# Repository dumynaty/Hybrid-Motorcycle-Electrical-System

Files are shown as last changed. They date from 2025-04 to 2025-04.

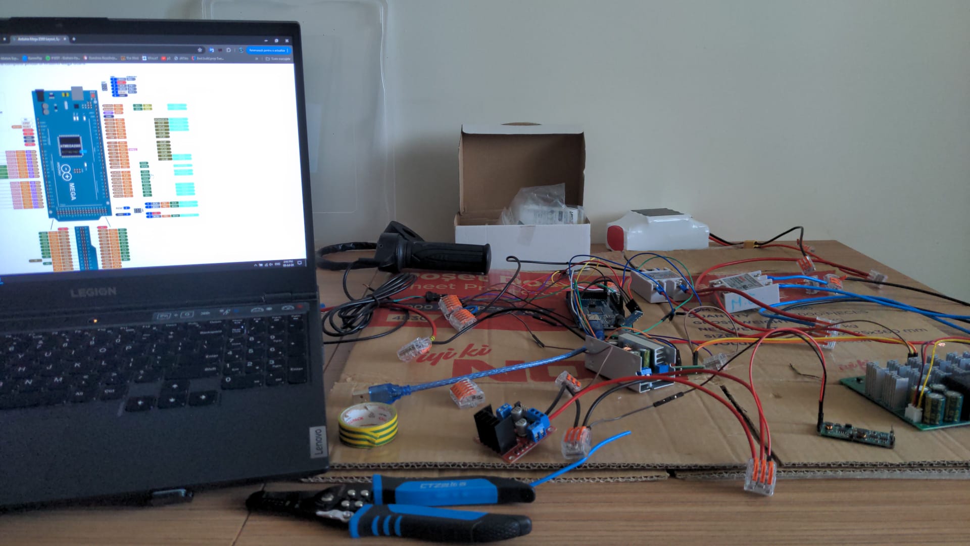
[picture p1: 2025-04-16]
Components/Images/Testing Image 1.png

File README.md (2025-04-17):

# Hybrid Motorcycle Electrical System

## Description
This project focuses on designing an electrical system for a motorcycle, combining a DC motor with a combustion engine to create a plug-in hybrid vehicle.

#### Note: Used as a thesis in Robotics Engineering. Some elements (3D models, technical drawings, sizing & load calculations etc.) have been left out.

### Overview elements
* Aim and conceptual background: read **Project Design** and **Thesis Description**
* Electrical system schematic: access **Fritzing** folder for schematic file or image
* Components used: access **Components** folder for list and images
* Integration logic: access **Code** folder

### General outline
Main components:
* Combustion engine and DC motor
* Additional motors for controlling the engine's gear and speed cable (worm gear, servo)
* Motor Drivers
* Battery to power the motor and other electrical components
* Ability to charge the battery during operation
* Sensors: Hall, Gyroscope, Voltage, Current
* Electronic switches (E-switches) to control current flow paths
* Voltage regulators
* Microcontrollers: Arduino Mega (program logic), ESP32 (Bluetooth communication)

### Functionality
The system is designed to accomplish the following:
* DC motor used as primary propulsion source at speeds up to 20 km/h
* Engine's power for higher speeds
* Smooth transition when switching power sources
* Using DC motor: throttle lever provides data to the microcontroller, which then regulates current delivery via the motor driver
* Using engine: throttle lever provides data to the microcontroller, which controls the clutch actuator motor and regulates the servomotor connected to the throttle cable and, under certain conditions, also initiates battery charging

### Further development possibilities
The system can be significantly improved by integrating the regulators, sensors, drivers, and other components into a single custom PCB.
Additional sensors may be added, such as a temperature sensor, to expand monitoring capabilities.
Further optimization of the microcontroller code can enhance performance and efficiency.
A visual interface can also be developed to display the data received via Bluetooth communication.

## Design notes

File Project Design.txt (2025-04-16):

	Initial Concept

This project aims to convert a regular pedal bicycle into a hybrid vehicle by integrating an 80cc combustion engine and an electric motor, allowing it to switch between them automatically based on wheel RPM data from a sensor. This optimizes energy consumption and performance in various road conditions.

Initially, an 80cc engine was planned, but due to reliability issues, it was replaced with a more robust 125cc Lifan engine. This engine includes a magneto that supplies 12V for charging and powering other components. The throttle and clutch require strong cables, so more powerful motors were chosen to control them.
The electric motor chosen is a 350W, 9.47Nm unit, controlled by a dedicated driver and a throttle handle connected to an Arduino Mega (upgraded from Uno for more complex functionality). The vehicle uses sensors (RPM and gyroscope) for automatic motor switching and safety. If the rider falls, the gyroscope cuts off power to the motors.
A UPS module (with a 18650 battery) ensures the Arduino remains powered at all times. An ESP32 module sends real-time data via Bluetooth to a smartphone — including motor RPM, battery status, etc.
Charging the batteries is managed using voltage regulators, e-switch modules, and safety measures (to prevent reverse current). The system is a carefully engineered blend of electrical and mechanical integration.

	Electrical Architecture
	
Key considerations in system architecture include:
Selecting the main electric motor, batteries, and microcontroller
Choosing motors for clutch and throttle cable control
Selecting appropriate motor drivers
Integrating a throttle (potentiometer-based)
RPM and tilt (gyro) sensors for control and safety
Voltage regulators (buck/boost) for component power needs
Modules for current monitoring and battery charging
UPS backup for Arduino
Wiring with proper connectors and terminal blocks

	Requirements Analysis & Hierarchy
	
The development process prioritized the following:
Correct selection and sizing of the main electric and combustion motors
Appropriate battery selection for power and autonomy
A microcontroller (Arduino Mega) to manage data and control flow
Motor drivers suited for the system's power requirements
Ergonomic speed throttle compatible with the handlebar
Sensors (RPM, gyroscope) for automatic control and safety
Voltage regulation modules to power components safely
Battery charging system design using boost converters, e-switches, and safety diodes
Reliable wiring and connectors to ensure stable power delivery
Testing and tuning will follow the schematic to ensure smooth operation.

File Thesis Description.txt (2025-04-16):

This bachelor's thesis focuses on designing a hybrid system for a motorcycle, combining an electric motor with a combustion engine to enhance energy efficiency and reduce emissions. The project addresses the global shift toward sustainable transport by offering a transitional solution between conventional and fully electric vehicles.

Main Goal:
To build an integrated system that automatically switches between electric and thermal propulsion based on real-time usage, ensuring efficient energy use, safe operation, and smooth performance.

Key Steps:

Identify and classify main and secondary components (motors, battery, driver, etc.).
Design the system based on vehicle weight and power requirements.
Use simulations, software tools, and physical testing for validation.

Outcomes:
A working hybrid prototype for small vehicles.
Lower emissions, better energy performance.
Demonstrated integration feasibility of hybrid tech in motorcycles.

Limitations:
Testing was limited to controlled environments.
Real-world performance still to be evaluated.

Impact:

Environmental: Reduced carbon footprint and air pollution.
Economic: Lower user costs, potential for market expansion.
Scientific: Contributes to the knowledge base on compact hybrid systems.

Originality:
Innovative integration approach tailored for motorcycles, offering a valuable framework for future development in green mobility tech.

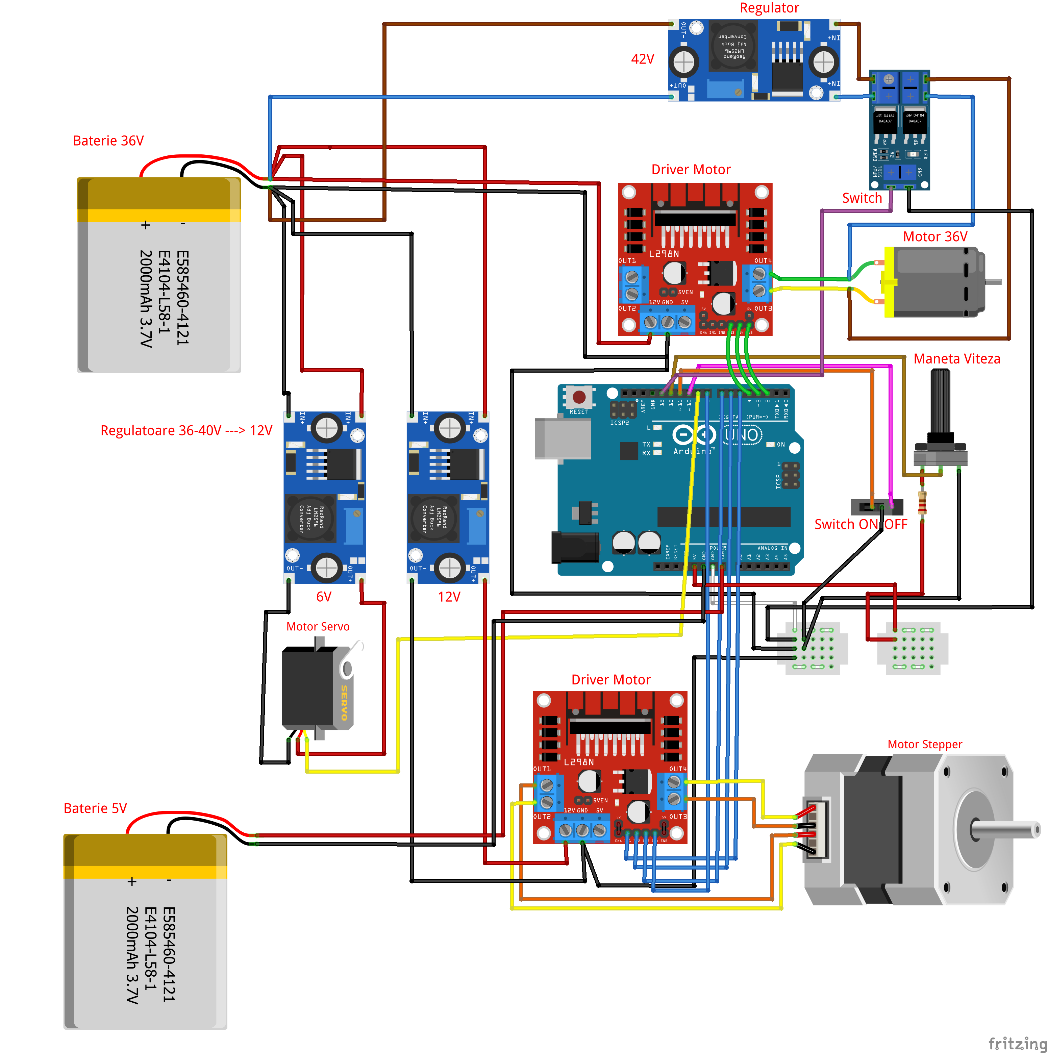
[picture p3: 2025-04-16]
Components/Images/Initial Design 5.png

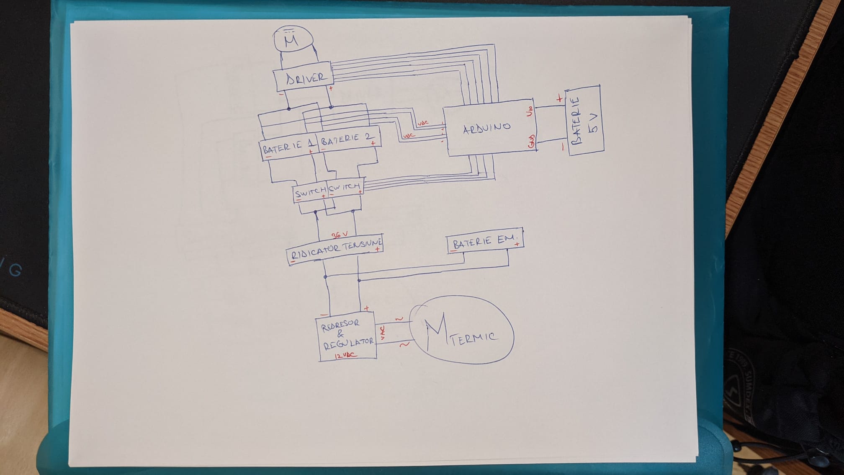
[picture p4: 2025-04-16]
Components/Images/Initial Design 2.jpeg

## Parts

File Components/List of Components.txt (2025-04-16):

Main Electric Motor: MY1016Z350W36V 36V 350W with reducer, torque 9.47Nm
Battery: Gares 36V 5800mAh battery with BMS and XT60 connectors
Development Board: Arduino Mega
Clutch Cable Motor: JCY-370 worm gear motor 12V
Pulley for JCY-370 Motor: 3D printed pulley
Gear Shift Cable Motor: MG996R 180-degree servo motor, 13kg·cm torque
Main Electric Motor Driver: 10-55V 60A motor driver
Gear Motor Driver: L298N driver
Throttle Lever: Simple e-bike throttle
Digital Potentiometer: X9C103S
Magnetic Sensor Module: Hall KY-003 + Magnet 20x10x5mm
Accelerometer and Gyroscope Module: MPU6050
Buck Voltage Regulator Module: Input voltage 8-60V, output 1-36V, 200W, 15A Max (with fan)
Buck Voltage Regulator Module: Input 4-35V, output 1.23-30V, 3A Max
Boost Voltage Regulator Module: Input 8.5-50VDC 400W, output 10-60VDC
Electric E-Switch: SSR40DD 220V 40A
Current Sensor Module: ACS712 30A
Voltage Sensor Module: SV 0-25V
Arduino + ESP32 Power Supply: UPS boost converter from 3.7V lithium battery to 9V with charging function
Backup Battery: Samsung Li-Ion 18650 battery 3.7V 2600mAh
Arduino Power Connector: Barrel connector
Bluetooth Module: ESP32 DevKit1 NodeMCU 30 Pins used for Bluetooth communication
Bluetooth Module Power Supply: LM2596 voltage regulator module
Cooling Components: Fans
Battery Circuit Switch: Rocker switch 30A
UPS Switch: Simple button
Charging Cable: Standard 42V power cable
Common Terminal Blocks: Wago 3-pin and 5-pin
Conductors: Wires of various sizes
Internal Combustion Engine Output: Charging relay (magneto + rectifier & 12V voltage regulator)

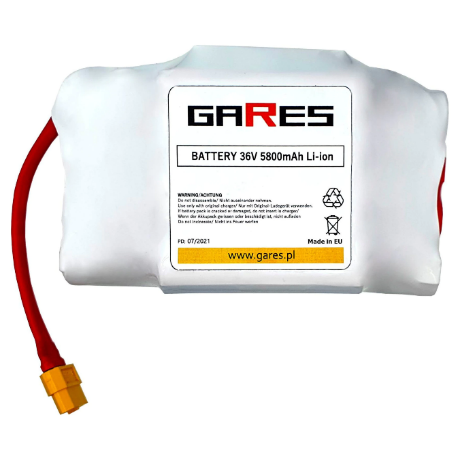
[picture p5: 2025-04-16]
Components/Images/Gares Battery 36V.png

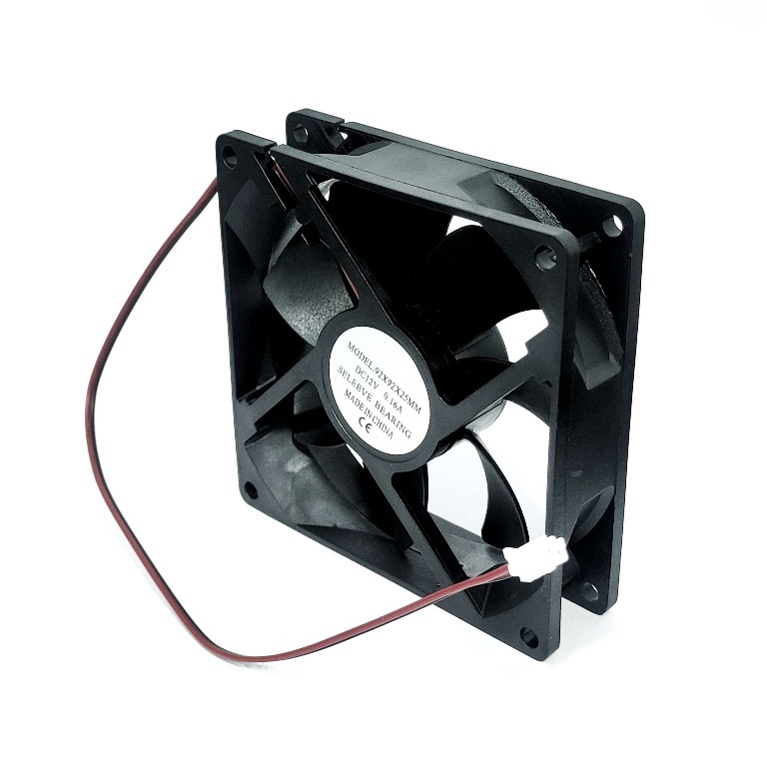
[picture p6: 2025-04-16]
Components/Images/Cooler.jpeg

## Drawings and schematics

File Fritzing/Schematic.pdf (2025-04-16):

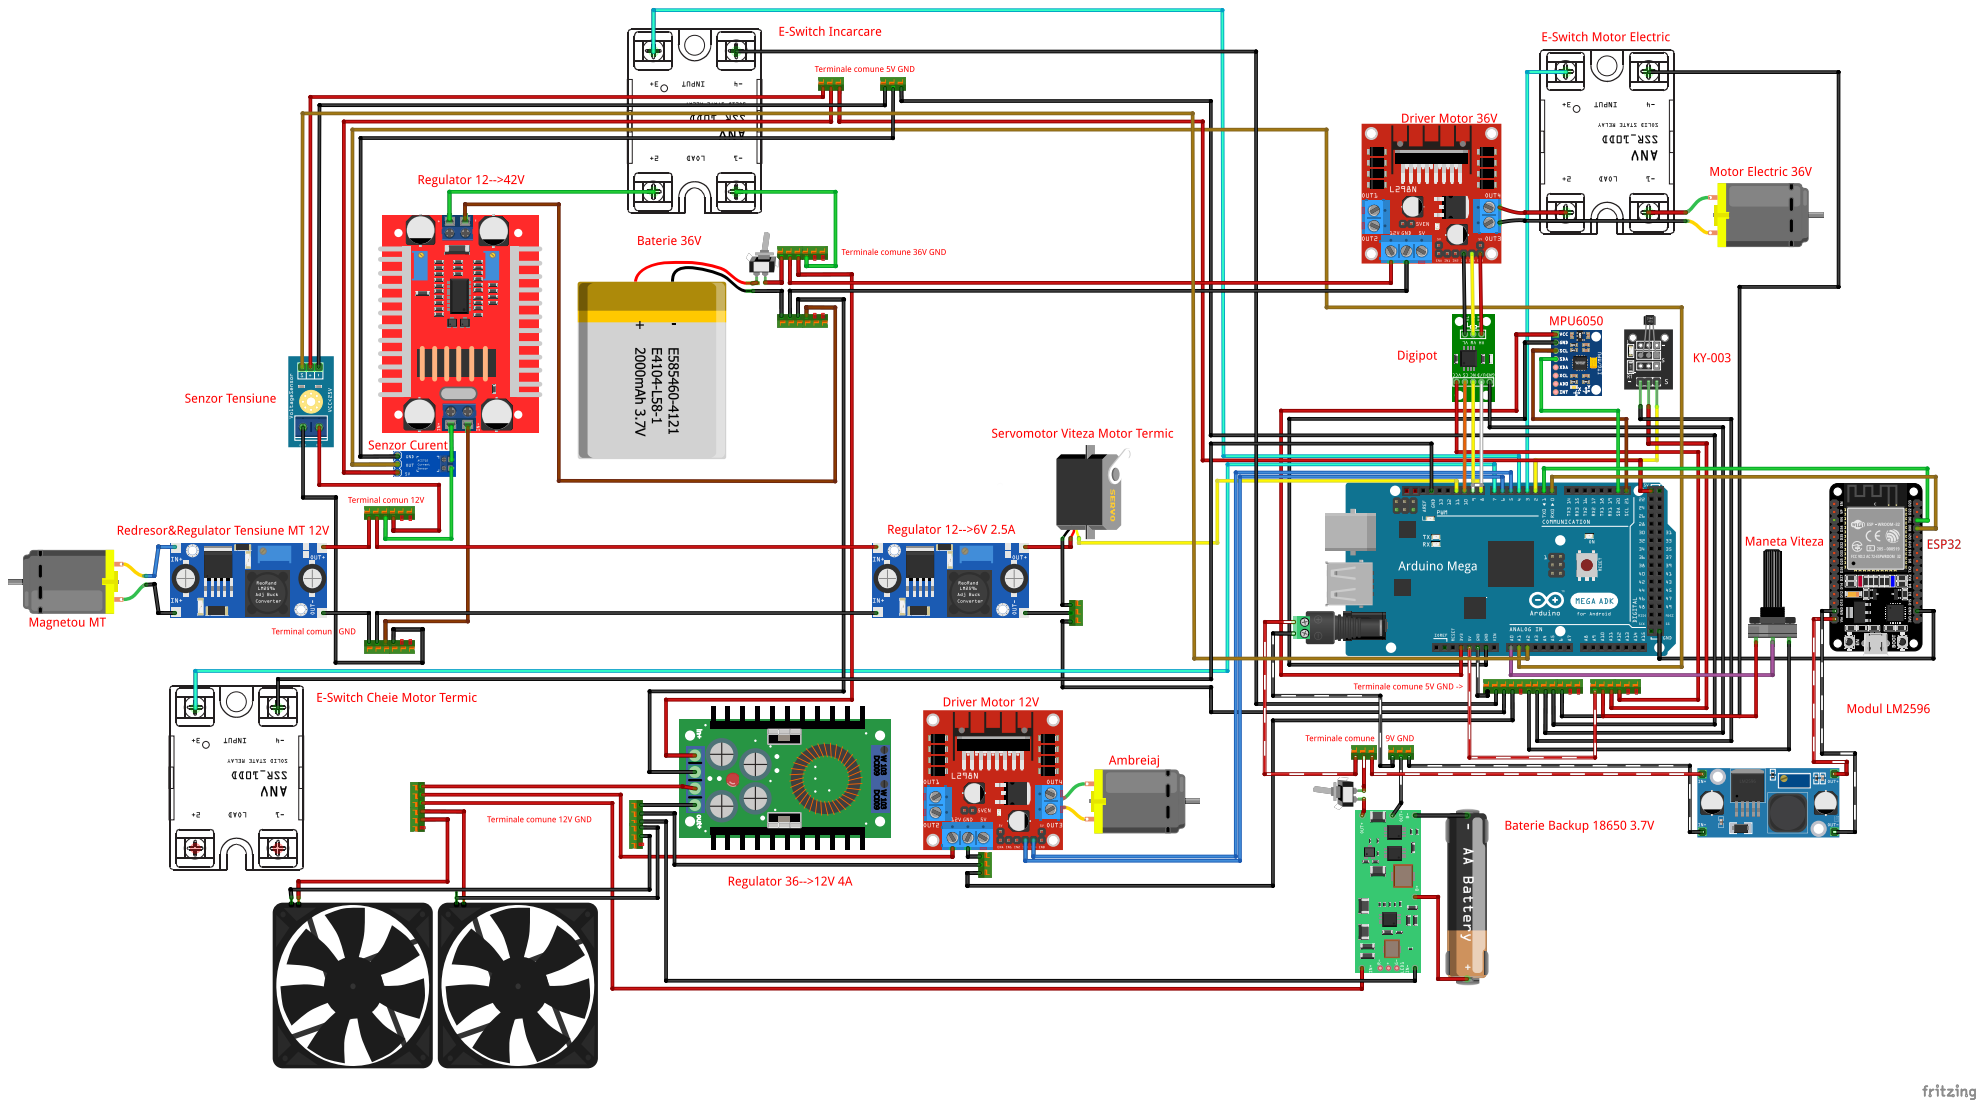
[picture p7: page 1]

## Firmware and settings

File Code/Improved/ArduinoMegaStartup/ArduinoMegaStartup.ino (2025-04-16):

// Timers Locations:
// Timer 0 - engine
// Timer 2 - servoSpeed
// Timer 3 - digipot
// Timer 4 - clutch
// Timer 5 - clutch
// Timer 6 - engine
// Timer 7 - Startup
// Timer 8 - Startup
// Timer 9 - Startup
// Timer 10 - Startup

#include <X9C10X.h> // Digipot Library
#include <Wire.h> // Wire library for SCA SDL
#include <MPU6050_light.h> // MPU6050 sensor Library
#include <Servo.h> // Servomotor Library

#define eSwitchElectricMotor 3
#define eSwitchEngine 7
#define eSwitchCharging 4

int speedLeverPin = A0; // Define the speedLeverPin pin to Arduino
Servo servoMotor; // Create servoMotor object
MPU6050 mpu(Wire); // Create MPU6050 Sensor object
bool mpuFailed = false; // Verification boolean for the MPU6050
X9C10X digipot(10000);  // Initialize the digipot with 10KΩ resistance

unsigned int RPM; // Define variable for RPM
bool engineIsRunning = false; // Engine running boolean
int clutchState = 0; // Set initial clutch state to 0. See clutch.ino for the 3 possible states
int eSwitchState = 1; // Set initial eSwitch state. See eSwitch.ino for the 5 possible states
bool switchingToEngine = false; // Define boolean for switching from DC motor to Engine
bool canChargeBattery = true; // Define boolean for the possibility of charging the battery

double voltmeterValue = 0;
float currentSensorValue;

bool clutchIsEngaging = false; // Boolean for engaging clutch
bool clutchIsDisengaging = false; // Boolean for disengaging clutch

unsigned long Timer[10] = {0}; // Initialize an array of Timer variables

void setup()
{
  // Set eSwitch pinmode to Output
  pinMode(eSwitchElectricMotor, OUTPUT);
  pinMode(eSwitchEngine, OUTPUT);
  pinMode(eSwitchCharging, OUTPUT);
  pinMode(speedLeverPin, INPUT);

  // Set Baud rate for Arduino and ESP
  Serial.begin(115200);
  Serial1.begin(115200);

  // Display start messsages
  Serial.println();
  Serial.println("Starting..");
  Serial2.println("Starting..");

  // Begin Initialization
  // Set inital E-Switches status On/Off
  SwitchElectric();
  // Set digipot position to 0
  digipotStartup();
  // Start MPU6050 sensor reading
  mpu6050Startup();
  // Start Interrupt for tachometer sensor
  tachometerStartup();
  // Initialize servoMotor
  servoStartup();

  // Display message when initialization has finished
  Serial.println("Setup complete!");
  Serial2.println("Setup Complete!");
}

void loop()
{
  voltmeterValue = getVoltage(); // Get voltmeter sensor voltage value
  debugTimer();                  // Send values to ESP32 and print them there
  ApplyESwitchState();            // Set the switches values
  mpu.update();                  // Update XYZ Angles from MPU6050 Sensor
  tachometer();                  // Update RPM from Tachometer

  if (eSwitchState == 1)         // Electric motor Run and check for Engine possibility to start
  {
    SwitchElectric();    
    digipotFunc();
    engineStart();
    if(switchingToEngine == true)
    {
      eSwitchState = 2;
      SwitchSwitchingToEngine();
    }
    if (clutchState == 0)
    {
      canChargeBattery = true;
    }
  }
  else if (eSwitchState == 2)     // Engage clutch and decrease electric motor digital pot value to 0
  {
    SwitchSwitchingToEngine();
    if (engineIsRunning == false) // If clutch isn't engaged yet, run on electric
    {
      digipotFunc();
    }
    clutchCheck();
    if (engineIsRunning == true) // If clutch is engaged start decreasing the electric motor power
    {
      eSwitchState = 3;
    }
  }
  else if (eSwitchState == 3)    // Run on engine
  {
    SwitchEngine();
    engineRun();
    electricDecrease();
    
    if (clutchState == 2)        // If speed is low and the clutch needs to disengage
    {
      clutchCheck();
      if (engineIsRunning == false)
      {
        eSwitchState = 1;
      }
    }

    if(switchingToEngine == false && canChargeBattery == true && voltmeterValue > 10)
    {
      if(setTime(10000, 9))
      {
        eSwitchState = 4;
      }
    }
  }
  else if (eSwitchState == 4)   // Charge battery and run on engine
  {
    SwitchCharging();
    engineRun();

    // If clutch will disengage cancel charging
    if (clutchState == 2)
    {
      canChargeBattery = false;
      clutchCheck();
      if (engineIsRunning == false)
      {
        eSwitchState = 1;
      }
    }
  }
  if (eSwitchState == 0)       // Shut every switch off
  {
    SwitchesOFF();
  }
}

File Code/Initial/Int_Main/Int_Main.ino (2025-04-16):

// Timer 0 - engine
// Timer 1 - DELETED
// Timer 2 - servoSpeed
// Timer 3 - digipot
// Timer 4 - clutch
// Timer 5 - clutch
// Timer 6 - engine
// Timer 7 - int_main
// Timer 8 - int_main
// Timer 9 - int_main
// Timer 10 - int_main
// Timer 20 - 
// Timer 21 -
// Timer 22 -
// Timer 23 -

#include <X9C10X.h> // Digipot Library
#include <Wire.h> // Wire library for SCA SDL
#include <MPU6050_light.h> // MPU6050 sensor Library
#include <Servo.h> // Servomotor Library

#define eSwitchElectric 3
#define eSwitchTermic 7
#define eSwitchIncarcare 4

Servo servoMotor;

int speedLever = A0; // The speedLever pin to Arduino
MPU6050 mpu(Wire); // Define MPU6050
bool mpuFailed = false;
X9C10X digipot(10000);  // Initialize the digipot with 10KΩ resistance

unsigned long RPM;

bool engine = false; // Initialize engine run variable

int clutch = 0;

int eSwitchValue = 0;

bool passing = false;

bool chargeP = true;

double voltmeterValue = 0;
float currentSensorValue;

bool debugEngaging = false;
bool debugDisengaging = false;

unsigned long startMillis[100] = {0};

void setup()
{
  pinMode(eSwitchElectric, OUTPUT);
  pinMode(eSwitchTermic, OUTPUT);
  pinMode(eSwitchIncarcare, OUTPUT);
  Serial.begin(115200);              // Changed Baud Rate
  Serial1.begin(115200);             // Start ESP32 communication through RX1 TX1 pins
  delay(100);
  Serial.println();
  Serial.println("Starting..");
  Serial2.println("Starting..");
  pinMode(speedLever, INPUT);
  eSwitchValue = 11;
  SwitchElectric();
  digipotStartup();
  mpuStartup();
  tachometerStartup();
  servoStartup();
  delay(100);
  Serial.println("Setup complete!");
  Serial2.println("Setup Complete!");
}

void loop()
{
  getVoltage();
  debugTimer();             // Send values to ESP32 and print them there
  switchesFunction();       // Set the switches values
  mpu.update();             // Update XYZ Angles from MPU6050 Sensor
  tachometer();             // Update RPM from Tachometer

  if (eSwitchValue == 11)               // Electric motor Run and check for Engine possibility to start
  {
    SwitchElectric();    
    digipotFunc();
    engineStart();
    if(passing == true)
    {
      eSwitchValue = 12;
      SwitchTrecere();
    }
    
  }
  else if (eSwitchValue == 12)          // Engage clutch and decrease electric motor digital pot value to 0
  {
    SwitchTrecere();
    if (engine == false)                // If clutch isn't engaged yet run on electric
    {
      digipotFunc();
    }
    clutchCheck();                      // clutchEngage(); returns engine = true;
    if (engine == true)                 // If cluth is engaged start decreasing electrical motor power
    {
      eSwitchValue = 13;
    }
  }
  else if (eSwitchValue == 13)          // Run on engine
  {
    SwitchTermic();
    engineRun();
    electricDecrease();
    
    // If speed is low and the clutch needs to disengage
    if (clutch == 2)
    {
      clutchCheck();
      if (engine == false)
      {
        eSwitchValue = 11;
      }
    }

    if(passing == false && chargeP == true && voltmeterValue > 10)
    {
      if(setTime(10000, 9))
      {
        eSwitchValue = 14;
      }
    }
  }
  else if (eSwitchValue == 14)          // Charge battery and run on engine
  {
    SwitchIncarcare();
    engineRun();

    if (clutch == 2)
    {
      chargeP = false;
      clutchCheck();
      if (engine == false)
      {
        eSwitchValue = 11;
      }
    }
  }
  if (eSwitchValue == 10)          // Shut every switch off
  {
    SwitchDecuplare();
  }

  /* Code for current monitoring of battery discharge to the motor 
  if (setTime(2000, 11) && currentSensorValue > 15 && digipot.getPosition() > 50)
  {
    digipot.setPosition(0);
    Serial.println("OVERCURRENT ERROR!!!");
  }
  */
}

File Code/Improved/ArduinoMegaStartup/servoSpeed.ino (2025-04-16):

void servoStartup() 
{
  servoMotor.attach(11); // Define the servoMotor's Pin
  servoMotor.write(0); // Set angle to 0
}

void servoSpeedFunc() 
{
  if (engineIsRunning == true)
  {
    int servoCurrentPosition = servoMotor.read();
    int servoNextPosition = map(speedLeverDCFunc(), 0, 99, 0, 180);
    
    if (servoNextPosition > servoCurrentPosition)       // If the speedLever wants to accelerate add +1 degree to the servoMotor each setTime(x, 2) ms
    {
      if (setTime(75, 2))
      {
        servoMotor.write(++servoCurrentPosition);
      }
    }
    else
    {
      servoMotor.write(servoNextPosition);              // If the speedLever wants to decelerate then decrease the angle of the Servo to the speedLever value 
    }
  }
}

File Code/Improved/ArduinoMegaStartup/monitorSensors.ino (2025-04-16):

// Voltage Sensor - Analog pin 2
int offset = 20;
int getVoltage() 
{
  double voltage = map(analogRead(A2), 0, 1023, 0, 2500) + offset; // Map 0-1023 to 0-2500 and add correction offset
  voltage /= 100; // Divide by 100 to get the decimal values
  return voltage;
}

// Current Sensor
#define VIN A1 // Define the Arduino pin A0 as voltage input (V in)
const float VCC = 5.0; // Supply voltage is from 4.5 to 5.5V. Normally 5V.
const int model = 2;   // Value for 30A module
float cutOffLimit = 1.01;
float sensitivity[] = { 0.185, 0.100, 0.066 };
const float QOV = 0.5 * VCC; // Set quiescent Output voltage of 0.5V
float voltage; // Internal variable for voltage

void readCurrentSensor() 
{
    float voltage_raw = (5.0 / 1023.0) * analogRead(VIN); // Read the voltage from sensor
    voltage = voltage_raw - QOV + 0.012; // 0.012 is a value to make voltage zero when there is no current
    currentSensorValue = voltage / sensitivity[model];
}
